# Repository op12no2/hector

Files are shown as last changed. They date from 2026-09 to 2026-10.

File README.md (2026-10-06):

## Hector

A little hexapod.

### Parts

- 12 off [SC09 Serial Bus Servo (2.3kg)](https://thepihut.com/products/serial-bus-servo-2-3kg)
- [M5Stack ATOM S3R](https://thepihut.com/products/atoms3r-development-kit-with-0-85-display-8mb-psram)
- [MPM3610 5V Buck Converter Breakout - 21V In 5V Out at 1.2A](https://thepihut.com/products/adafruit-mpm3610-5v-buck-converter-breakout-21v-in-5v-out-at-1-2a)
- 2S LiPo
- Small Schottky diode (SS14, 1N5817), a switch (or XT30 plug) and optionally a ~5 A fuse
- Sensor TBD

### Wiring

See [wiring.md](wiring.md): the ATOM drives the bus through the adapter's UART header (jumper in A), powered from the battery through the buck and a diode, which leaves its USB-C free for flashing.

### Chassis

See `cad` folder above. I used a Bambu P2S.

### Software

`hector.c` drives the servos from a Raspberry Pi 5 through a [Waveshare Serial Bus Servo Driver Board](https://thepihut.com/products/serial-bus-servo-driver-board) (USB, jumper in B). It's a copy of the [servo](https://github.com/op12no2/servo) tester, so all of its commands (`ping`, `stat`, `move`, `torque`, `limits`, ...) work here too, plus the hexapod commands below.

```
make
./hector [/dev/ttyACM0] [baud]     # default 1000000
```

The same `hector.c` also builds for the ATOM S3R (ESP-IDF, in `atom/`), which drives the bus through the adapter's UART header (jumper in A, see [wiring.md](wiring.md)), with the REPL on the ATOM's USB:

```
cd atom
source ~/esp/esp-idf/export.sh
idf.py build
idf.py -p /dev/serial/by-id/usb-Espressif_* flash monitor     # ctrl-] leaves the monitor
```

At power-on the ATOM runs the checks, stands up unless something failed, runs the standing checks, then shows its face: two eyes and a mouth, turned so the mouth points at its front (someone standing there sees it upright). The eyes blink and glance about while it waits for a command; if something's wrong the whites go yellow or red, the mouth goes flat or frowns, and the problem shows along the bottom. While it waits it also watches the servos (a low or flat battery, heat, error bits, a load held high, a servo not replying: shown under the eyes, and for the serious ones it sits down), and while it's standing, lift it at an edge and put it down: it walks away from that edge (away from you) for 5 seconds, with the current gait and stride. It sets off within about half a second of being put down. The gap opposite the lifted edge becomes its front, and the face turns there while it's still lifted, so you can see where it will go. Sliding it along the desk does nothing. There are no safety stops for now (nothing waits for hands to be clear, and it doesn't go limp if a leg meets something while walking): a key stops a walk and ctrl-c freezes it. Knocked over, it sits. Every command works the same way there; `quit` has nothing to quit to, and changes to `offset[]` last until the ATOM resets. Any terminal on its USB port works as well as `idf.py monitor` (e.g. `picocom /dev/ttyACM0`), but opening the port with `idf.py monitor` resets the ATOM.

Leg *n* is hip (yaw) servo *n* and lift servo *n*+6. Where each leg is, and which way each servo turns, is set in `legs[]` at the top of the hexapod section of `hector.c`.

`offset[]`, just above it, is a per-servo offset added to every goal position sent, by `move` as well as the hexapod commands, so with an offset of 20 on servo 7, `move 7 511` sends 531. The lifts' offsets come from `calibrate`. `offset` and `calibrate` change it until you exit; they print the table as a line of C to paste into `hector.c` to keep it. `pos`, `stat` and `move`'s check report the servo's actual position, with the offset included; `ww` to the goal register doesn't add it.

| Command | Description |
|---|---|
| `stand [ms]` | all feet down, hips centred, taking ms (default 1000) |
| `front [1-6]` | show or set the walk's front: gap k, between legs k and k+1 (gap 6, legs 6 and 1, after a reset). A tip sets it too (it walks away from the lifted edge), and the face turns to it |
| `sit [ms]` | all six lifts up to 1000, taking ms (default 1000), the same as `move 7-12 1000 1000`: the body sits on the ground with the legs pointing up inside it, so there's no load on the servos. Do it before switching off; `stand` gets up again |
| `legtest [1-6]` | each leg in turn (or one, by hip id): lift servo up to 700, forward 80, back, down to its stance pose; the other legs stay where they are |
| `ident [id]` | twitch each id (default 1-12) in turn, a second apart, to see which servo has which id: 30 steps up from where it is and back; it prints which leg `legs[]` says the id belongs to |
| `offset [id val]` | show the per-servo offsets, or set one; the change lasts until exit |
| `calibrate` | stand, then nudge the lift offsets, a step or two at a time from where they are, until all six feet carry the same load (within 1.5%); prints the offset table to paste into `hector.c` |
| `walk [cycles] [stride] [turn]` | stand, then walk with the current gait; stride < 0 walks backwards, turn > 0 turns left (stride 0 turns on the spot); with no cycles it walks until a key is pressed; a key stops it gracefully (legs step back to centre), ctrl-c freezes it where it is; afterwards it prints each servo's peak load (a servo held over 80% for 4 s drops to 20% torque) and the longest tick (they should be 20 ms). The face holds still while it walks |
| `set [name value]` | list or set walk parameters (below) |
| `loads [secs]` | stream every servo's load and position error (goal and position both read from the servo) as fast as the bus allows, about 80 sweeps of all 12 a second, for secs seconds (default 10) or until a key; reads only, so stand first. The ATOM's screen shows the seconds, to time presses by |
| `imu [secs]` | stream the ATOM's IMU (BMI270) at 50 lines a second: acceleration (g) and rotation (deg/s), with x towards the gap between legs 1 and 2, y 90° anticlockwise from it seen from above and z up, and the tilt from the first reading; default 10 s, or until a key |
| `selftest` | the checks it runs at startup, again (they only read, nothing moves). Before standing (the go/no-go for standing up): the screen and the IMU answer (ATOM only), every servo replies, battery (warns under 7.0 V, fails under 6.6), temperature, error bits, overload protection at the defaults, the gains (P 15, D 15, I 1 on the lifts and 0 on the hips), positions inside the range the legs are driven over. Standing (only if `stand` ran last, not `sit`): the load on each foot (warns if one is over 5% off the mean: calibrate), sag (a foot pushed up over 6 steps from its goal), level (IMU, warns over 5°), the highest load on any servo, the battery under load. On the ATOM each check also goes up on the screen as it runs, then the eyes come back, their whites yellow with warnings or red with failures, with the first problem under them |

| Parameter | Default | |
|---|---|---|
| `gait` | tripod | `wave` (1 leg up at a time), `ripple` (2) or `tripod` (3) |
| `step` | 800 | ms each leg spends in the air (a cycle is 6 steps in wave, 3 in ripple, 2 in tripod) |
| `stride` | 50 | hip swing either side of centre, servo steps (0.29° each) |
| `lift` | 70 | foot lift during a step, steps |
| `height` | 0 | legs this far below centre when standing, -150..50: > 0 raises the body, < 0 lowers it with the legs splayed (the legs reach the chassis at about 50 below) |

First run: prop the body up so the feet are off the ground, `legtest`, and check that each leg lifts *up* and swings *forward*, and that the leg that moves is the one named. Fix `legs[]` if not. Then put it down and `walk 2`.

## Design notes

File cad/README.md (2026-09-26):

## CAD

Each part is here twice: `.step` (the model, for measuring or editing) and `.stl` (the same part laid flat for printing). Units are mm. The STEP files come from Open CASCADE 7.8.

| Part | What it is |
|---|---|
| `04_six_leg_platform` | the body: a 220 mm disc, 3 mm thick, with six spokes carrying the hip servo pockets, and a central wiring cage |
| `06_electronics_lid` | a 100 mm disc that closes the top of the cage |
| `02_hip_cradle` | bolts to a hip servo's horn and holds that leg's lift servo on its side (×6) |
| `03_fixed_leg` | a 4 mm plate on the lift servo's horn, running out about 28 mm and then bending down to a rounded foot (×6) |
| `05_one_hip_assembly` | the body and lid with one leg fitted (hip and lift servos, horns, cradle, leg), as named parts; STEP only |

The parts share one coordinate frame: body centre on the z axis, the underside of the plate at z = 0 (the assembly sits 0.8 mm lower than the loose cradle and leg files).

### Body

- **Plate:** an outer ring (r 102–110) joined to a hub by six spokes, with big lightening windows between them. Each spoke carries a hip servo pocket, and two 3 mm ribs on top run along it either side of the servo. A 10 mm hole in the middle.
- **Cage:** a tube, 100 mm across and 1.6 mm wall, standing 63 mm above the underside of the plate, with rows of slots round it for wires. The lid's 4 mm spigot drops into its top.
- **Inside the cage:** six pairs of M3 holes, 8 mm apart, on a 70 mm circle (one pair in line with each leg), for the electronics.

### How it goes together

- **Legs:** six, 60° apart. The middle legs are on the x axis, so forward is along y. The front and rear legs are 60° either side of the middle ones.
- **Hip servos:** each sits in a pocket, hanging under the plate (to 18.5 mm below it), with its mounting holes (M2) 70 and 98.5 mm from the centre. The shaft is 90 mm from the centre (the SC09's shaft is 5.65 mm off the midpoint of its mounting holes). The hip axis is vertical.
- **Lift servos:** the cradle holds each one with its axis horizontal, directly above the hip axis, 12 mm above the cradle's underside and 23 mm above the underside of the plate.
- **Leg plates:** each sits about 18 mm along the lift axis from the hip axis, so the foot is offset sideways from the hip, not straight out from it.
- **Horns:** the servo horns take a 6 mm hub with two M2 screws 19.8 mm apart (the holes in the cradle base and the leg).

### Leg geometry

With the leg as drawn (taken to be the 511 pose), the bottom of the foot is 42.5 mm out from the lift axis and 81 mm below it, 91.5 mm in all (the old, shorter leg was 41 and 71). The lift servo turns the whole leg about that axis, so `height` in `hector.c` (one step = 0.293°) moves the foot like this, with the body's height off the ground on level feet:

| `height` | Foot out from lift axis | Foot below lift axis | Plate underside off the ground | Hip servos off the ground |
|---|---|---|---|---|
| +50 | 21 | 89 | 66 | 47 |
| 0 | 42 | 81 | 58 | 39 |
| −60 | 65 | 64 | 41 | 23 |
| −100 | 77 | 50 | 27 | 8 |
| −120 | 81 | 42 | 19 | 0 |

Below about −120 the hip servos, not the feet, touch the ground. The second column is the lever arm the lift servo works against: its torque is the weight on that foot times this distance. A lower, more splayed body means more torque, up to 91.5 mm when the foot is level with the axis.

### Clearances

Measured by turning the parts in the assembly, so only as good as the "as drawn = 511" assumption:

- **Lift, foot down (`height` > 0):** the leg reaches the outer ring of the plate at about 26° (89 steps). The old body measured 92 steps the same way, yet the legs met the chassis at about 50 on the robot, so the drawn pose is probably not exactly 511; expect about the same margin as before.
- **Lift, foot up:** nothing in the way.
- **Hip, towards the side of the hip the leg plate is on:** the leg's lower half reaches the outer ring, sooner the lower the foot: about 61 steps at `height` +50, 123 at 0, 177 at −60 and 218 at −100 (the old body: 75, 137 and 198). The other way it's clear to about 90°. All six legs are fitted the same way round, so that's the same sense of rotation for every hip (anticlockwise from above in these files): forward on one side of the robot and back on the other. As `hip_dir` is −1 on the left and +1 on the right, it's also either a higher position for every hip or a lower one.
- **Neighbouring legs:** they don't meet, with each hip turned up to 118° towards the other.

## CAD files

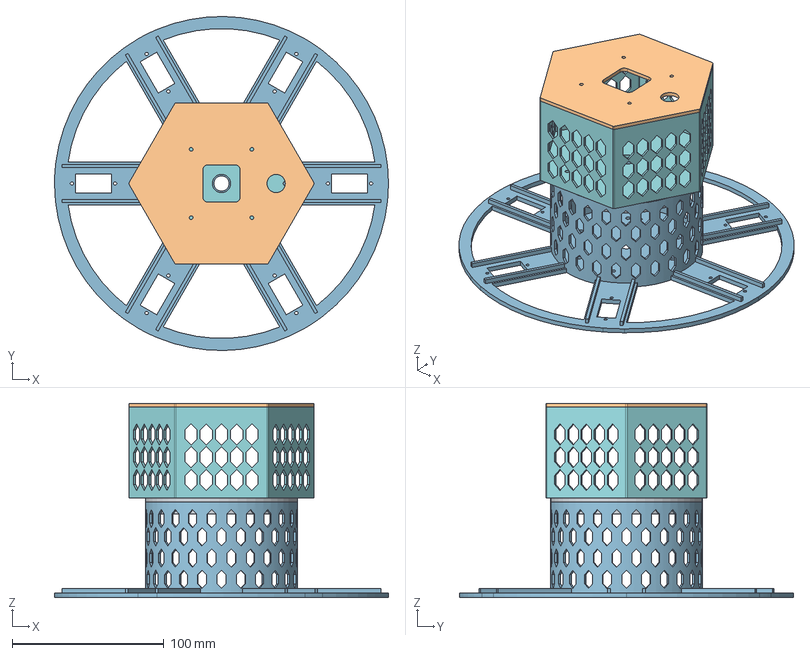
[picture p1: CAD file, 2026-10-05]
cad/11_extended_body_assembly.step
220.0 x 220.0 x 127.8 mm
adapter
upper_cage
hex_lid

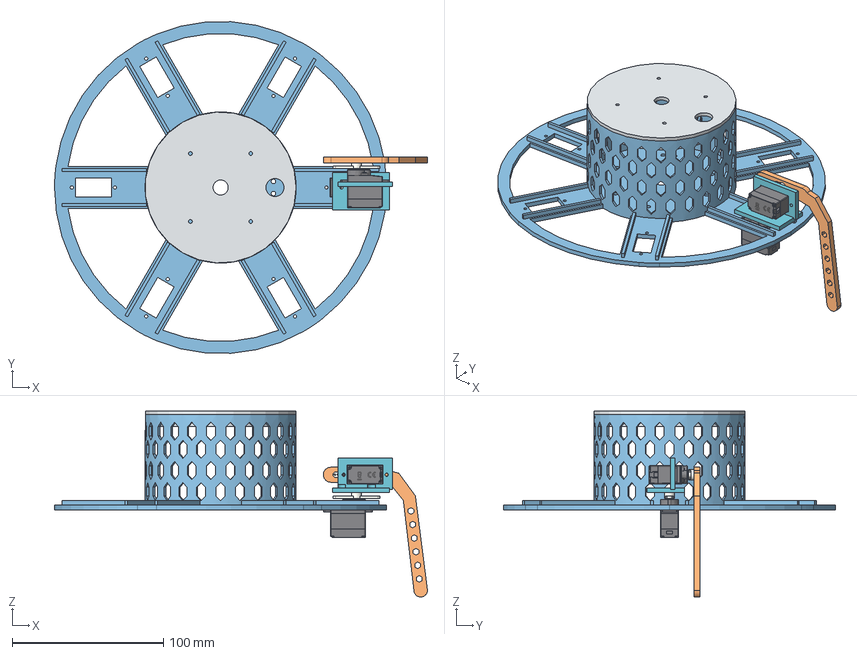
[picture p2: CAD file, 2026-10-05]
cad/05_one_hip_assembly.step
247.0 x 219.6 x 123.2 mm
lid
cradle
leg
yaw_servo
pitch_servo
yaw_horn
pitch_horn

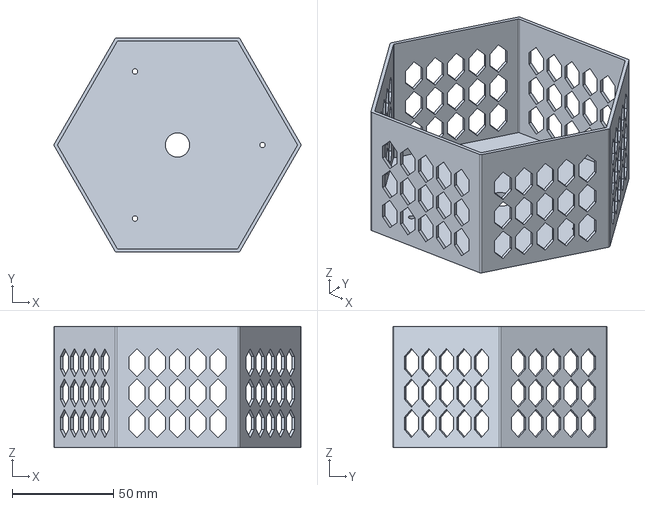
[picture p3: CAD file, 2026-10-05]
cad/07_hex_upper_cage.step
122.1 x 106.0 x 60.0 mm

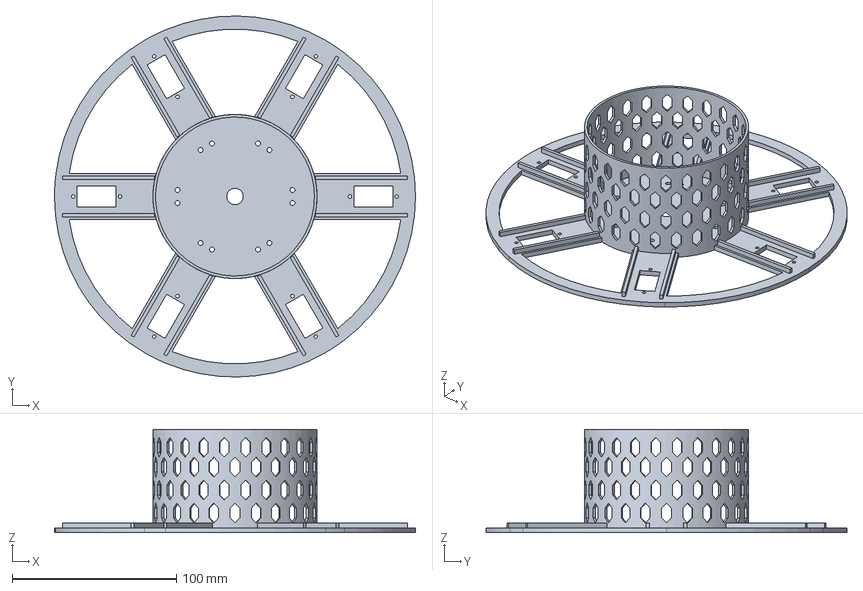
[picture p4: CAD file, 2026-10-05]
cad/04_six_leg_platform.step
220.0 x 220.0 x 63.0 mm

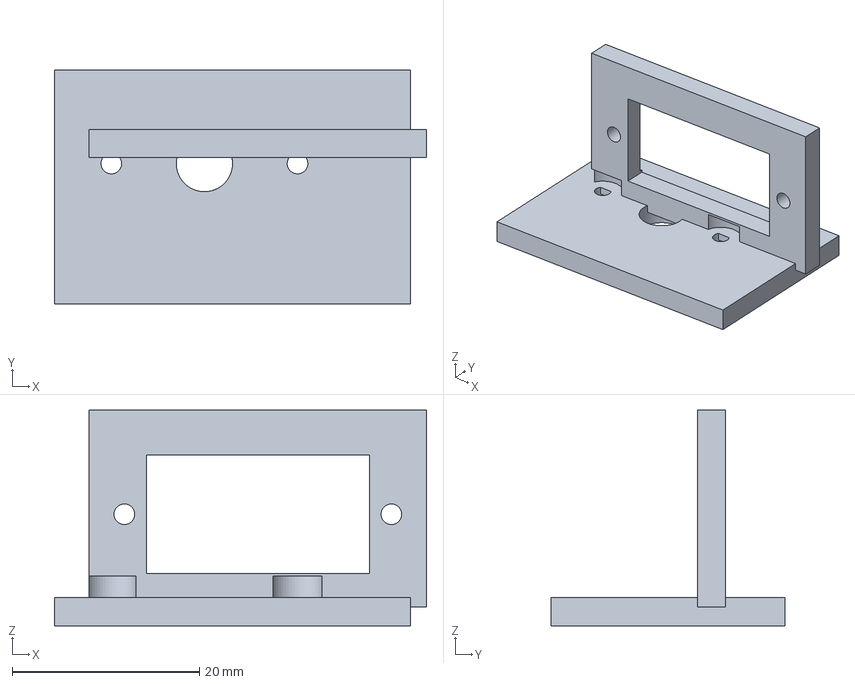
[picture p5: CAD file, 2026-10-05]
cad/02_hip_cradle.step
39.7 x 25.0 x 23.0 mm

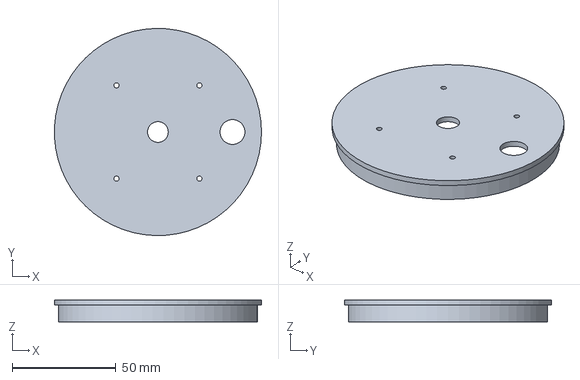
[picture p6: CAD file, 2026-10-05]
cad/06_electronics_lid.step
99.9 x 100.0 x 10.4 mm

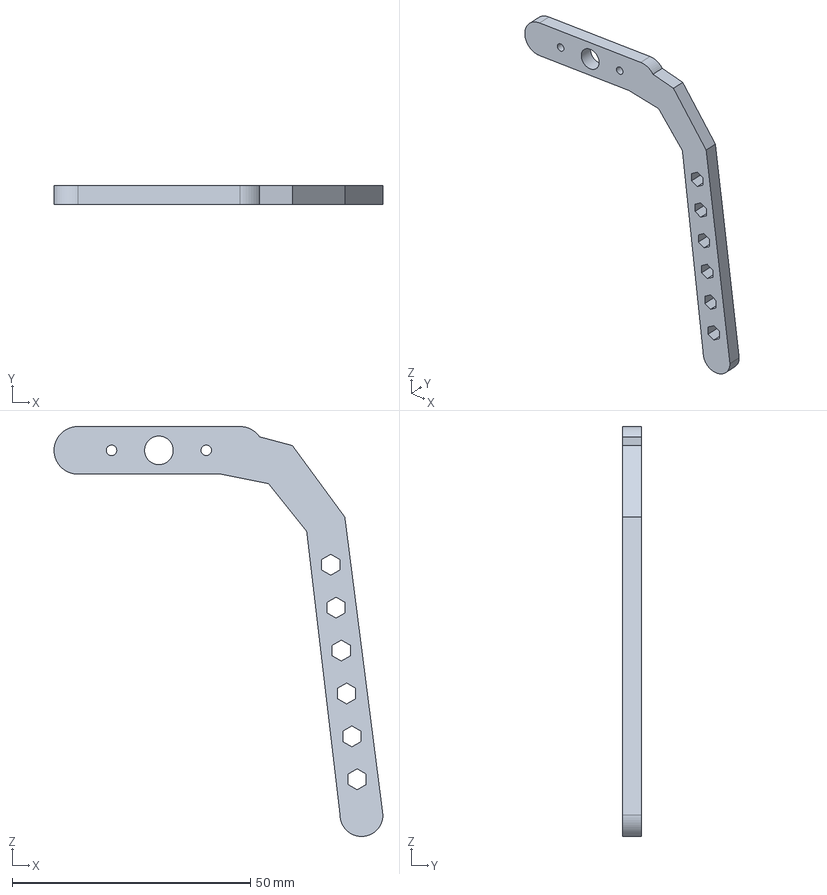
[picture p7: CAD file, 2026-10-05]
cad/03_fixed_leg.step
69.0 x 4.00 x 86.0 mm

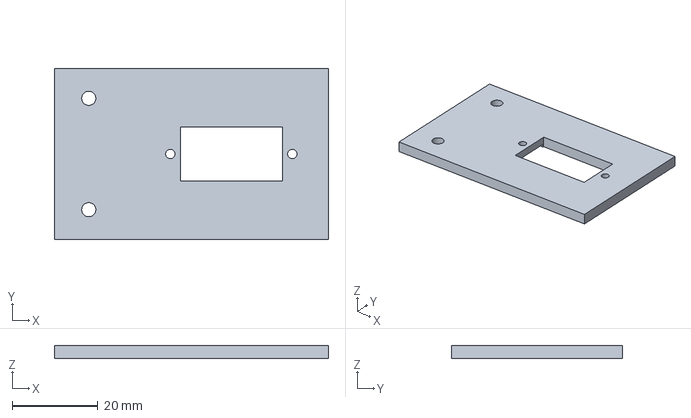
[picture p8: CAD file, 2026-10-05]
cad/01_bench_mount.step
64.0 x 40.0 x 3.00 mm

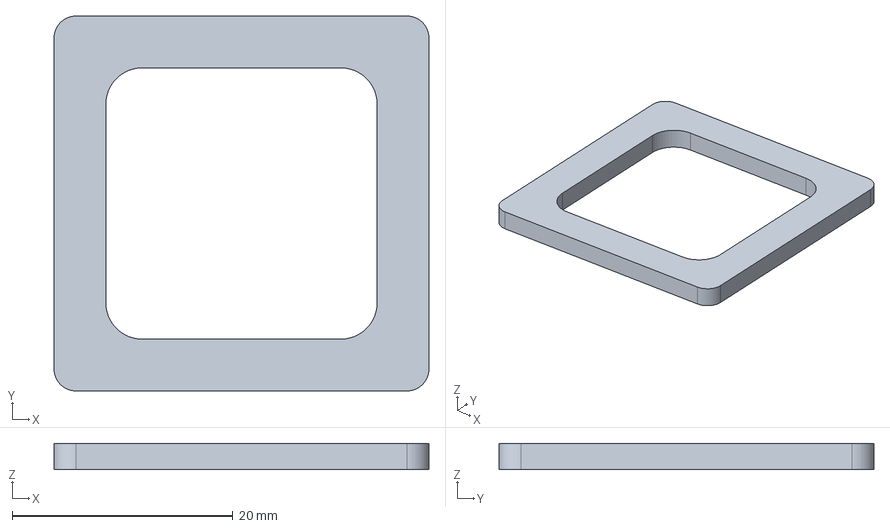
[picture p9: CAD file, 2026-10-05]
cad/10_atom_fit_test.step
34.0 x 34.0 x 2.40 mm

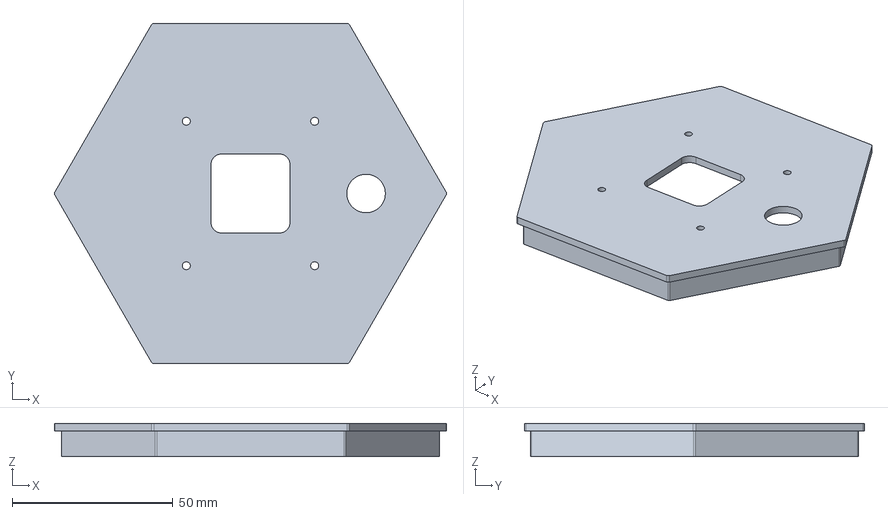
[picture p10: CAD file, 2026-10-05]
cad/09_hex_atom_lid.step
122.1 x 106.0 x 10.4 mm

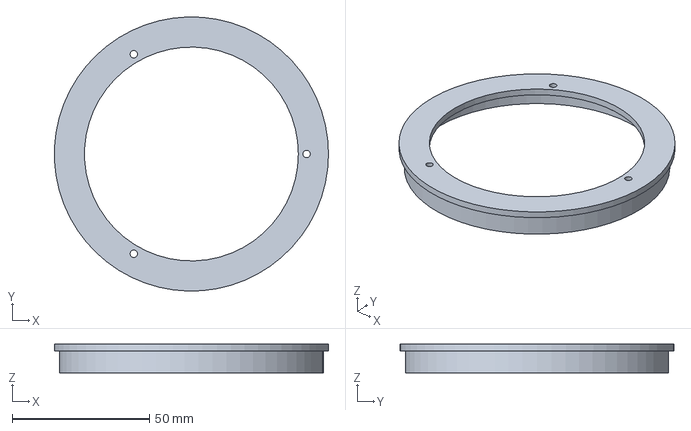
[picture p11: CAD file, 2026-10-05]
cad/08_circular_adapter.step
99.9 x 100.0 x 10.4 mm

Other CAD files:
cad/01_bench_mount.stl
cad/02_hip_cradle.stl
cad/03_fixed_leg.stl
cad/04_six_leg_platform.stl
cad/06_electronics_lid.stl
cad/07_hex_upper_cage.stl
cad/08_circular_adapter.stl
cad/09_hex_atom_lid.stl
cad/10_atom_fit_test.stl

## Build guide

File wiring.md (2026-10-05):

## Wiring: ATOM S3R

wiring

The ATOM talks to the bus over a GPIO UART into the adapter's UART header (H2), with the adapter's jumper in **A**. That leaves the ATOM's USB-C free for flashing and the console, even while it walks (tethered). The Pi's USB lead can stay plugged into the adapter: the jumper picks which one drives the bus (**A** = H2, the ATOM; **B** = USB, the Pi).

### Wires

| From | To | |
|---|---|---|
| battery + | SW1, F1, then adapter + **and** U1 Vin | VBAT, 20 AWG or thicker to the adapter |
| battery − | adapter − **and** U1 GND | |
| U1 5V | D1 anode | |
| D1 cathode | ATOM 5V | about 4.7 V |
| U1 GND | ATOM GND | |
| ATOM G38 (TX) | H2 TXD | |
| ATOM G39 (RX) | H2 RXD | |
| ATOM GND | H2 GND | run it with TX and RX |
| U1 En | nothing | pulled up to Vin on the breakout |

G39, G38, 5V and GND are the ATOM's right-hand header, in that order, so a single 4-way housing takes all of them. That leaves Port A (Grove: G2 SDA, G1 SCL, 5V, GND) for the sensor, and G5–G8 on the other header free.

H2 is a 3-pin header, GND, RXD, TXD. The names are from the host's side, so it's RXD to RX and TXD to TX, not crossed ("RX-RX, TX-TX" in Waveshare's wiki). If nothing replies, swapping them does no harm.

In code: `Serial1.begin(1000000, SERIAL_8N1, 39, 38);` (rx, tx).

### Why

- **The ATOM needs the buck.** Its 5V pin goes straight to its 5 V rail (the same net as USB VBUS, behind a 6 V polyfuse) and from there to a 5.5 V-max 3.3 V regulator, so 8.4 V from the battery would kill it. The adapter does have a 5 V buck and a 3.3 V regulator on board, but only for its own logic: they aren't brought out. U1 (the MPM3610 in the parts list) takes 6–21 V and gives 5 V at 1.2 A, plenty for the ATOM and a sensor.
- **D1** (any small Schottky, e.g. SS14 or 1N5817). Because the ATOM's 5V pin is its USB VBUS, with the battery on and USB plugged in, U1 and the computer's USB port would be wired together. With D1, U1 gives about 4.7 V; USB's 5 V wins when it's plugged in and D1 blocks it from feeding back into U1. Without D1, never plug USB in with the battery on.
- **No level shifting.** The adapter's UART side is 3.3 V (74LVC1G125/126 buffers on its own 3.3 V regulator), the same as the ESP32-S3. While the ATOM is resetting and G38 floats, the adapter's transmit enable is pulled off, so the bus just stays in receive.
- **Not the USB port.** The ATOM's USB-C is its only way to flash and see a console. Using it for the bus would mean USB host mode and a CH343 driver on the ESP32-S3, and unplugging the adapter every time you flash.
- **Battery voltage** comes from the servos' voltage register (0x3E, as `stat` and `check_servos()` read it), so no divider on an ADC pin. 2S is low at about 7.0 V under load.
- **SW1 and F1.** SW1 (or an XT30 plug) switches the servos and the ATOM together; it carries all the servo current, so a few amps. F1 is optional, but a LiPo will melt wire in a short, and the wiring cage is tight; about 5 A (the adapter is rated 6 A).

### Bringing it up

1. Before connecting the ATOM: battery on, check U1 + D1 give about 4.7 V, positive on the D1 cathode side. U1 has no reverse-polarity protection (the adapter does).
2. Connect the ATOM. It should boot from the battery, with or without USB.
3. Jumper to A, then flash `atom/` (see the README) and `ping` (2026-10-02: all 12 servos replied, with USB powering the ATOM and the buck's 5V lead off while D1 was on order; D1 was fitted by 2026-10-05).
4. Back to the Pi: jumper to B. The ATOM can stay wired.

### Sources

- [ATOM S3R](https://docs.m5stack.com/en/core/AtomS3R): [schematic](https://m5stack-doc.oss-cn-shenzhen.aliyuncs.com/680/Sch_M5_AtomS3R_v0.4.1.pdf), [pin map](https://m5stack-doc.oss-cn-shenzhen.aliyuncs.com/680/C126_PinMap_01.jpg)
- [Bus Servo Adapter (A)](https://www.waveshare.com/wiki/Bus_Servo_Adapter_(A)): [schematic](https://files.waveshare.com/wiki/Bus_Servo_Adapter_A/Bus_Servo_Adapter_A.pdf), [wiring example](https://docs.waveshare.com/Bus_Servo_Adapter_A/Product-Wiring-Example)
- [MPM3610 breakout](https://www.adafruit.com/product/4739): [PCB files](https://github.com/adafruit/Adafruit-MPM3610-PCB) (pins GND, 5V, Vin, En; En pulled up to Vin)

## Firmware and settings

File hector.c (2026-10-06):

/*
 * hector.c - Hector the hexapod: 12 Waveshare SC09 bus servos via a
 * Waveshare Bus Servo Adapter (A) / USB serial. Started as a copy of
 * ../servo/servo.c (the generic servo tester) and keeps all its commands;
 * the hexapod commands (stand, sit, front, legtest, ident, offset, calibrate,
 * walk, set, loads, imu, selftest) are at the end.
 *
 * Build:  make
 * Run:    ./hector [/dev/ttyACM0] [baud]
 * Then type commands on stdin ("help" lists them).
 *
 * The same file builds for the ATOM S3R (ESP-IDF, atom/): the bus is then
 * UART1 on G38/G39 into the adapter's UART header and the console is the
 * ATOM's USB. Only the I/O section below differs (ESP_PLATFORM).
 *
 * Protocol:
 *   TX: FF FF ID LEN INSTR PARAM... CHK     LEN = nparams + 2
 *   RX: FF FF ID LEN ERR   PARAM... CHK
 *   CHK = ~(ID + LEN + INSTR/ERR + sum(PARAM)) & 0xFF
 * 16-bit registers are high byte first.
 */
#include <errno.h>
#include <math.h>
#include <stdarg.h>
#include <stdio.h>
#include <stdlib.h>
#include <string.h>
#include <time.h>
#include <unistd.h>
#ifdef ESP_PLATFORM
#include "driver/gpio.h"
#include "driver/i2c_master.h"
#include "driver/spi_master.h"
#include "driver/uart.h"
#include "driver/usb_serial_jtag.h"
#include "driver/usb_serial_jtag_vfs.h"
#include "freertos/FreeRTOS.h"
#include "freertos/task.h"
#else
#include <fcntl.h>
#include <signal.h>
#include <termios.h>
#include <sys/select.h>
#include <sys/time.h>
#endif

#define INST_PING       0x01
#define INST_READ       0x02
#define INST_WRITE      0x03
#define INST_SYNC_WRITE 0x83
#define BROADCAST       0xFE

/* SC09 register map */
#define REG_ID            0x05
#define REG_MIN_ANGLE     0x09  /* u16 */
#define REG_MAX_ANGLE     0x0B  /* u16 */
#define REG_DEADZONE_CW   0x1A
#define REG_DEADZONE_CCW  0x1B
#define REG_TORQUE_ENABLE 0x28
#define REG_GOAL_POS      0x2A  /* u16 */
#define REG_GOAL_TIME     0x2C  /* u16 */
#define REG_GOAL_SPEED    0x2E  /* u16 */
#define REG_LOCK          0x30  /* EPROM lock: 1=locked, 0=unlocked */
#define REG_PRESENT_POS   0x38  /* u16 */
#define REG_PRESENT_SPEED 0x3A  /* u16 */
#define REG_PRESENT_LOAD  0x3C  /* u16 */
#define REG_VOLTAGE       0x3E
#define REG_TEMP          0x3F
#define REG_MOVING        0x42

static int verbose = 0;
static int timeout_ms = 50;

/* 16-bit register values are high byte first */
static int get16(const unsigned char *b) { return b[0] << 8 | b[1]; }
static void put16(unsigned char *b, int v) { b[0] = v >> 8; b[1] = v; }

static void die(const char *fmt, ...)
{
    va_list ap; va_start(ap, fmt); vfprintf(stderr, fmt, ap); va_end(ap);
    fputc('\n', stderr); exit(1);
}

/*
 * ---- I/O ----
 * The servo bus (open_port, bus_flush, bus_write, read_bytes), the console
 * (con_*), timing (msleep, tick_*), the screen (scr_*) and the IMU (imu_*):
 * the last two are the ATOM's, stubs on the Pi. Everything else is the same on the Pi and the ATOM.
 */
#ifdef ESP_PLATFORM

/* ATOM S3R: UART1, TX G38 to the adapter's H2 TXD, RX G39 from its RXD (jumper in A) */
#define BUS_UART UART_NUM_1
#define BUS_TX   38
#define BUS_RX   39
#define BUS_ECHO 0      /* the H2 link doesn't loop TX back to RX, so txrx() doesn't read for an echo (which costs a timeout per write) */

static void open_port(const char *dev, int baud)
{
    (void)dev;
    uart_config_t c = {
        .baud_rate = baud, .data_bits = UART_DATA_8_BITS, .parity = UART_PARITY_DISABLE,
        .stop_bits = UART_STOP_BITS_1, .flow_ctrl = UART_HW_FLOWCTRL_DISABLE, .source_clk = UART_SCLK_DEFAULT,
    };
    if (uart_driver_install(BUS_UART, 1024, 0, 0, NULL, 0) != ESP_OK || uart_param_config(BUS_UART, &c) != ESP_OK ||
        uart_set_pin(BUS_UART, BUS_TX, BUS_RX, UART_PIN_NO_CHANGE, UART_PIN_NO_CHANGE) != ESP_OK)
        die("uart setup failed");
    gpio_set_pull_mode(BUS_RX, GPIO_PULLUP_ONLY);
}

static void bus_flush(void) { uart_flush_input(BUS_UART); }

static void bus_write(const unsigned char *b, int n)
{
    uart_write_bytes(BUS_UART, b, n);
    uart_wait_tx_done(BUS_UART, portMAX_DELAY);
}

/* read n bytes or time out; returns bytes read */
static int read_bytes(unsigned char *buf, int n, int ms)
{
    int r = uart_read_bytes(BUS_UART, buf, n, pdMS_TO_TICKS(ms));
    return r < 0 ? 0 : r;
}

/*
 * The console is the ATOM's USB (USB-Serial/JTAG). It has no termios and no
 * SIGINT, so it is always "raw", and ctrl-c arrives as a byte (walk checks).
 */
static int con_block = 1;

static void con_init(void)
{
    usb_serial_jtag_driver_config_t c = USB_SERIAL_JTAG_DRIVER_CONFIG_DEFAULT();
    usb_serial_jtag_driver_install(&c);
    usb_serial_jtag_vfs_use_driver();
}

static int con_tty(void) { return 1; }
static void con_raw(int block) { con_block = block; }
static void con_restore(void) { con_block = 1; }

/* next byte; with con_raw(0), -1 if there isn't one */
static int con_getc(void)
{
    unsigned char c;
    return usb_serial_jtag_read_bytes(&c, 1, con_block ? portMAX_DELAY : 0) == 1 ? c : -1;
}

/* next byte within ms, or -2 if none came (for the idle loop) */
static int con_getc_ms(int ms)
{
    unsigned char c;
    return usb_serial_jtag_read_bytes(&c, 1, pdMS_TO_TICKS(ms)) == 1 ? c : -2;
}

/* drop typed-ahead input */
static void con_drop(void)
{
    unsigned char c;
    while (usb_serial_jtag_read_bytes(&c, 1, 0) == 1) ;
}

static volatile int halted;
static void sigint_catch(void) {}
static void sigint_restore(void) {}

static void msleep(int ms) { vTaskDelay(pdMS_TO_TICKS(ms)); }

/* fixed-rate ticks for walk: tick_start, then tick_wait(ms) each tick; tick_start again to resync */
static TickType_t tick_last;
static void tick_start(void) { tick_last = xTaskGetTickCount(); }
static void tick_wait(int ms) { xTaskDelayUntil(&tick_last, pdMS_TO_TICKS(ms)); }

/*
 * The screen: 0.85" 128x128 on SPI (MOSI G21, SCLK G15, CS G14, DC G42, RST G48).
 * The panel is a GC9107, or an ST7735S on some batches, told apart by RDDID as
 * M5GFX does (init sequences and offsets are from M5GFX too). The backlight is
 * an LP5562 LED driver on the internal I2C (SDA G45, SCL G0), which the IMU shares.
 * Drawing goes into fb[], and scr_show() sends all of it (32 KB, about 7 ms).
 */
#define LCD_HOST SPI3_HOST
#define LCD_MOSI 21
#define LCD_SCLK 15
#define LCD_CS   14
#define LCD_DC   42
#define LCD_RST  48
#define SYS_SDA  45     /* the internal I2C: backlight and IMU */
#define SYS_SCL  0
#define BL_ADDR  0x30   /* LP5562 */
#define BL_LEVEL 160    /* 0..255 */

static spi_device_handle_t lcd;
static int lcd_x0, lcd_y0;              /* where the 128x128 window starts in the controller's memory */
static uint16_t fb[128 * 128];          /* RGB565, byte-swapped: sent high byte first */

/*
 * Init lists: command, number of parameters (| 0x80 if a delay follows),
 * parameters, then the delay in ms (255 = 500); 0xFF ends the list.
 */
static const unsigned char gc9107_init[] = {
    0xFE, 0x80, 5,
    0xEF, 0x80, 5,
    0xB0, 1, 0xC0,  0xB2, 1, 0x2F,  0xB3, 1, 0x03,  0xB6, 1, 0x19,  0xB7, 1, 0x01,
    0xAC, 1, 0xCB,  0xAB, 1, 0x0E,  0xB4, 1, 0x04,  0xA8, 1, 0x19,  0xB8, 1, 0x08,
    0xE8, 1, 0x24,  0xE9, 1, 0x48,  0xEA, 1, 0x22,  0xC6, 1, 0x30,  0xC7, 1, 0x18,
    0xF0, 14, 0x01, 0x2B, 0x23, 0x3C, 0xB7, 0x12, 0x17, 0x60, 0x00, 0x06, 0x0C, 0x17, 0x12, 0x1F,
    0xF1, 14, 0x05, 0x2E, 0x2D, 0x44, 0xD6, 0x15, 0x17, 0xA0, 0x02, 0x0D, 0x0D, 0x1A, 0x18, 0x1F,
    0x11, 0x80, 120,                    /* sleep out */
    0x29, 0,                            /* display on */
    0x3A, 1, 0x55,                      /* 16-bit colour */
    0x36, 1, 0x08,                      /* MADCTL: BGR */
    0x20, 0,                            /* inversion off */
    0xFF,
};
static const unsigned char st7735s_init[] = {
    0x01, 0x80, 150,                    /* software reset */
    0x11, 0x80, 255,                    /* sleep out */
    0xB1, 3, 0x01, 0x2C, 0x2D,
    0xB2, 3, 0x01, 0x2C, 0x2D,
    0xB3, 6, 0x01, 0x2C, 0x2D, 0x01, 0x2C, 0x2D,
    0xB4, 1, 0x07,
    0xC0, 3, 0xA2, 0x02, 0x84,  0xC1, 1, 0xC5,  0xC2, 2, 0x0A, 0x00,  0xC3, 2, 0x8A, 0x2A,
    0xC4, 2, 0x8A, 0xEE,  0xC5, 1, 0x0E,
    0xE0, 16, 0x02, 0x1C, 0x07, 0x12, 0x37, 0x32, 0x29, 0x2D, 0x29, 0x25, 0x2B, 0x39, 0x00, 0x01, 0x03, 0x10,
    0xE1, 16, 0x03, 0x1D, 0x07, 0x06, 0x2E, 0x2C, 0x29, 0x2D, 0x2E, 0x2E, 0x37, 0x3F, 0x00, 0x00, 0x02, 0x10,
    0x13, 0x80, 10,                     /* normal display on */
    0x29, 0x80, 100,                    /* display on */
    0x3A, 1, 0x55,                      /* 16-bit colour */
    0x36, 1, 0xDC,                      /* MADCTL: rotated 180, BGR */
    0x21, 0,                            /* inversion on */
    0xFF,
};

/* the panel's id (RDDID, 3-wire: one dummy bit, then 32 bits back on MOSI) */
static uint32_t lcd_id(int hz)
{
    spi_device_interface_config_t d = {
        .command_bits = 8, .dummy_bits = 1, .clock_speed_hz = hz, .spics_io_num = LCD_CS,
        .queue_size = 1, .flags = SPI_DEVICE_3WIRE | SPI_DEVICE_HALFDUPLEX,
    };
    spi_device_handle_t h;
    if (spi_bus_add_device(LCD_HOST, &d, &h) != ESP_OK) return 0;
    spi_transaction_t t = { .cmd = 0x04, .rxlength = 32, .flags = SPI_TRANS_USE_RXDATA };
    uint32_t id = 0;
    gpio_set_level(LCD_DC, 0);
    if (spi_device_polling_transmit(h, &t) == ESP_OK)
        id = t.rx_data[0] | t.rx_data[1] << 8 | t.rx_data[2] << 16 | (uint32_t)t.rx_data[3] << 24;
    spi_bus_remove_device(h);
    return id;
}

/* dc 0 = command, 1 = data */
static void lcd_send(int dc, const void *p, int n)
{
    spi_transaction_t t = { .length = n * 8, .tx_buffer = p };
    gpio_set_level(LCD_DC, dc);
    spi_device_polling_transmit(lcd, &t);
}

static void lcd_cmds(const unsigned char *c)
{
    while (*c != 0xFF) {
        unsigned char cmd = *c++, n = *c++, par[32];
        if ((n & 0x7F) > sizeof par) die("lcd init list: %d parameters", n & 0x7F);
        lcd_send(0, &cmd, 1);
        memcpy(par, c, n & 0x7F);           /* via RAM: DMA can't read flash */
        if (n & 0x7F) lcd_send(1, par, n & 0x7F);
        c += n & 0x7F;
        if (n & 0x80) { int ms = *c++; msleep(ms == 255 ? 500 : ms); }
    }
}

/*
 * 5x7 font, ' ' to '~', a byte per column, bit 0 at the top. From Adafruit GFX's
 * glcdfont.c: Copyright (c) 2012 Adafruit Industries. All rights reserved.
 * BSD licence: redistributions must keep this notice. THIS SOFTWARE IS PROVIDED
 * BY THE COPYRIGHT HOLDERS AND CONTRIBUTORS "AS IS" AND ANY EXPRESS OR IMPLIED
 * WARRANTIES ARE DISCLAIMED (full text in Adafruit-GFX-Library's glcdfont.c).
 */
static const unsigned char font5x7[95][5] = {
    { 0x00, 0x00, 0x00, 0x00, 0x00 },  /* ' ' */
    { 0x00, 0x00, 0x5F, 0x00, 0x00 },  /* '!' */
    { 0x00, 0x07, 0x00, 0x07, 0x00 },  /* '"' */
    { 0x14, 0x7F, 0x14, 0x7F, 0x14 },  /* '#' */
    { 0x24, 0x2A, 0x7F, 0x2A, 0x12 },  /* '$' */
    { 0x23, 0x13, 0x08, 0x64, 0x62 },  /* '%' */
    { 0x36, 0x49, 0x56, 0x20, 0x50 },  /* '&' */
    { 0x00, 0x08, 0x07, 0x03, 0x00 },  /* "'" */
    { 0x00, 0x1C, 0x22, 0x41, 0x00 },  /* '(' */
    { 0x00, 0x41, 0x22, 0x1C, 0x00 },  /* ')' */
    { 0x2A, 0x1C, 0x7F, 0x1C, 0x2A },  /* '*' */
    { 0x08, 0x08, 0x3E, 0x08, 0x08 },  /* '+' */
    { 0x00, 0x80, 0x70, 0x30, 0x00 },  /* ',' */
    { 0x08, 0x08, 0x08, 0x08, 0x08 },  /* '-' */
    { 0x00, 0x00, 0x60, 0x60, 0x00 },  /* '.' */
    { 0x20, 0x10, 0x08, 0x04, 0x02 },  /* '/' */
    { 0x3E, 0x51, 0x49, 0x45, 0x3E },  /* '0' */
    { 0x00, 0x42, 0x7F, 0x40, 0x00 },  /* '1' */
    { 0x72, 0x49, 0x49, 0x49, 0x46 },  /* '2' */
    { 0x21, 0x41, 0x49, 0x4D, 0x33 },  /* '3' */
    { 0x18, 0x14, 0x12, 0x7F, 0x10 },  /* '4' */
    { 0x27, 0x45, 0x45, 0x45, 0x39 },  /* '5' */
    { 0x3C, 0x4A, 0x49, 0x49, 0x31 },  /* '6' */
    { 0x41, 0x21, 0x11, 0x09, 0x07 },  /* '7' */
    { 0x36, 0x49, 0x49, 0x49, 0x36 },  /* '8' */
    { 0x46, 0x49, 0x49, 0x29, 0x1E },  /* '9' */
    { 0x00, 0x00, 0x14, 0x00, 0x00 },  /* ':' */
    { 0x00, 0x40, 0x34, 0x00, 0x00 },  /* ';' */
    { 0x00, 0x08, 0x14, 0x22, 0x41 },  /* '<' */
    { 0x14, 0x14, 0x14, 0x14, 0x14 },  /* '=' */
    { 0x00, 0x41, 0x22, 0x14, 0x08 },  /* '>' */
    { 0x02, 0x01, 0x59, 0x09, 0x06 },  /* '?' */
    { 0x3E, 0x41, 0x5D, 0x59, 0x4E },  /* '@' */
    { 0x7C, 0x12, 0x11, 0x12, 0x7C },  /* 'A' */
    { 0x7F, 0x49, 0x49, 0x49, 0x36 },  /* 'B' */
    { 0x3E, 0x41, 0x41, 0x41, 0x22 },  /* 'C' */
    { 0x7F, 0x41, 0x41, 0x41, 0x3E },  /* 'D' */
    { 0x7F, 0x49, 0x49, 0x49, 0x41 },  /* 'E' */
    { 0x7F, 0x09, 0x09, 0x09, 0x01 },  /* 'F' */
    { 0x3E, 0x41, 0x41, 0x51, 0x73 },  /* 'G' */
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
};

static void scr_clear(void) { memset(fb, 0, sizeof fb); }

/* s at pixel (x, y), each font pixel scale x scale; characters are 6 x 8 font pixels */
static void scr_text(int x, int y, int scale, int colour, const char *s)
{
    uint16_t c = (colour >> 8 & 0xFF) | (colour & 0xFF) << 8;
    for (; *s; s++, x += 6 * scale) {
        int ch = (unsigned char)*s;
        const unsigned char *g = font5x7[ch < 0x20 || ch > 0x7E ? '?' - 0x20 : ch - 0x20];
        for (int col = 0; col < 5; col++)
            for (int row = 0; row < 8; row++)
                if (g[col] >> row & 1)
                    for (int dy = 0; dy < scale; dy++)
                        for (int dx = 0; dx < scale; dx++) {
                            int px = x + col * scale + dx, py = y + row * scale + dy;
                            if (px >= 0 && px < 128 && py >= 0 && py < 128) fb[py * 128 + px] = c;
                        }
    }
}

static void scr_pixel(int x, int y, int colour)
{
    if (x >= 0 && x < 128 && y >= 0 && y < 128) fb[y * 128 + x] = (colour >> 8 & 0xFF) | (colour & 0xFF) << 8;
}

/* send fb to the panel */
static void scr_show(void)
{
    unsigned char cmd, w[4] = { 0, lcd_x0, 0, lcd_x0 + 127 };
    cmd = 0x2A; lcd_send(0, &cmd, 1); lcd_send(1, w, 4);           /* CASET */
    w[1] = lcd_y0; w[3] = lcd_y0 + 127;
    cmd = 0x2B; lcd_send(0, &cmd, 1); lcd_send(1, w, 4);           /* RASET */
    cmd = 0x2C; lcd_send(0, &cmd, 1); lcd_send(1, fb, sizeof fb);  /* RAMWR */
}

/* a device on the internal I2C (SDA G45, SCL G0: the backlight and the IMU), setting the bus up first time */
static int sys_i2c_dev(int addr, i2c_master_dev_handle_t *d)
{
    static i2c_master_bus_handle_t bus;
    i2c_master_bus_config_t b = {
        .i2c_port = -1, .sda_io_num = SYS_SDA, .scl_io_num = SYS_SCL, .clk_source = I2C_CLK_SRC_DEFAULT,
        .glitch_ignore_cnt = 7, .flags.enable_internal_pullup = 1,
    };
    i2c_device_config_t c = { .dev_addr_length = I2C_ADDR_BIT_LEN_7, .device_address = addr, .scl_speed_hz = 400000 };
    if (!bus && i2c_new_master_bus(&b, &bus) != ESP_OK) { bus = NULL; return -1; }
    return i2c_master_bus_add_device(bus, &c, d) == ESP_OK ? 0 : -1;
}

/* LP5562: enable, internal clock, all channels from their PWM registers, W (the backlight) to level */
static int bl_init(int level)
{
    i2c_master_dev_handle_t d;
    if (sys_i2c_dev(BL_ADDR, &d)) return -1;
    unsigned char w[][2] = { { 0x00, 0x40 }, { 0x08, 0x01 }, { 0x70, 0x00 }, { 0x0E, level } };
    for (int i = 0; i < 4; i++) {
        if (i2c_master_transmit(d, w[i], 2, 50) != ESP_OK) return -1;
        if (i == 0) msleep(1);
    }
    return 0;
}

/* set up the screen and clear it; what it is, or NULL if there isn't one. *ok = 0 if the backlight didn't answer */
static const char *scr_init(int *ok)
{
    static char what[48];
    spi_bus_config_t b = {
        .mosi_io_num = LCD_MOSI, .miso_io_num = -1, .sclk_io_num = LCD_SCLK,
        .quadwp_io_num = -1, .quadhd_io_num = -1, .max_transfer_sz = sizeof fb,
    };
    if (spi_bus_initialize(LCD_HOST, &b, SPI_DMA_CH_AUTO) != ESP_OK) return NULL;
    gpio_reset_pin(LCD_DC);
    gpio_set_direction(LCD_DC, GPIO_MODE_OUTPUT);
    gpio_reset_pin(LCD_RST);
    gpio_set_direction(LCD_RST, GPIO_MODE_OUTPUT);
    gpio_set_level(LCD_RST, 0);
    msleep(10);
    gpio_set_level(LCD_RST, 1);
    msleep(120);

    /* some GC9107s only answer slowly; an ST7735S answers at the first speed */
    uint32_t id = lcd_id(8000000);
    int st = (id & 0xFFFF) == 0x7683 || (id & 0xFFFF) == 0x897C, gc = (id & 0xFFFFFF) == 0x079100;
    if (!st && !gc) {
        id = lcd_id(100000);
        gc = (id & 0xFFFFFF) == 0x079100;
    }
    spi_device_interface_config_t d = { .clock_speed_hz = 40000000, .spics_io_num = LCD_CS, .queue_size = 1 };
    if (spi_bus_add_device(LCD_HOST, &d, &lcd) != ESP_OK) return NULL;
    lcd_cmds(st ? st7735s_init : gc9107_init);
    lcd_x0 = st ? 2 : 0;
    lcd_y0 = st ? 3 : 32;
    snprintf(what, sizeof what, "%s (id %06lx%s)", st ? "ST7735S" : "GC9107",
             (unsigned long)(id & 0xFFFFFF), st || gc ? "" : ", not recognised");
    scr_clear();
    scr_show();
    *ok = bl_init(BL_LEVEL) == 0 && (st || gc);
    return what;
}

/*
 * The IMU: a Bosch BMI270 (accelerometer and gyro) at 0x68 on the internal
 * I2C. It needs Bosch's 8 KB configuration file uploaded at every start-up.
 * Accelerometer +-4 g at 100 Hz, gyro +-500 deg/s at 200 Hz. imu_read()
 * turns the readings into the robot's axes: +x towards the gap between legs
 * 1 and 2, +y 90 degrees anticlockwise from that (seen from above), +z up.
 * Legs 1-6 (hip ids) go clockwise round the body, so leg k points at
 * 30 - 60 (k - 1) degrees. The ATOM lies flat on the leg 1-4 axis, the
 * chip's +x pointing at leg 4, IMU_YAW (found by tipping the robot up at
 * each gap between legs).
 */
#define IMU_ADDR 0x68
#define IMU_YAW  -150.0         /* deg, anticlockwise from the 1-2 gap: where the chip's +x points */
#include "atom/bmi270_config.h"

static i2c_master_dev_handle_t imu;
static double imu_c, imu_s;             /* cos and sin of IMU_YAW, from imu_init() */

static int imu_wr(int reg, int v)
{
    unsigned char w[2] = { reg, v };
    return i2c_master_transmit(imu, w, 2, 50) == ESP_OK ? 0 : -1;
}

static int imu_rd(int reg, unsigned char *b, int n)
{
    unsigned char r = reg;
    return i2c_master_transmit_receive(imu, &r, 1, b, n, 50) == ESP_OK ? 0 : -1;
}

/* the IMU didn't answer or start: drop its handle, so imu_read() fails rather than reading an unconfigured chip */
static int imu_fail(void)
{
    if (imu) i2c_master_bus_rm_device(imu);
    imu = NULL;
    return -1;
}

/* 0 if it's there and its config loaded, -1 if not (1 = no IMU on this host, the Pi's stub) */
static int imu_init(void)
{
    unsigned char id = 0, st = 0, buf[1 + 256];
    imu_c = cos(IMU_YAW * M_PI / 180);
    imu_s = sin(IMU_YAW * M_PI / 180);
    if (sys_i2c_dev(IMU_ADDR, &imu)) return -1;
    if (imu_rd(0x00, &id, 1) || id != 0x24) return imu_fail();                         /* CHIP_ID */
    imu_wr(0x7E, 0xB6);                         /* CMD: soft reset (needs 2 ms) */
    msleep(5);
    imu_wr(0x7C, 0x00);                         /* PWR_CONF: advanced power save off, for the upload (450 us) */
    msleep(5);
    imu_wr(0x59, 0x00);                         /* INIT_CTRL: start of config load */
    for (int i = 0; i < (int)sizeof bmi270_config_file; i += 256) {
        unsigned char a[3] = { 0x5B, (i / 2) & 0x0F, (i / 2) >> 4 };       /* INIT_ADDR_0/1, in words */
        buf[0] = 0x5E;                                                      /* INIT_DATA */
        memcpy(buf + 1, bmi270_config_file + i, 256);
        if (i2c_master_transmit(imu, a, 3, 50) != ESP_OK || i2c_master_transmit(imu, buf, sizeof buf, 100) != ESP_OK) return imu_fail();
    }
    imu_wr(0x59, 0x01);                         /* INIT_CTRL: config load done */
    for (int i = 0; i < 20 && (st & 0x0F) != 1; i++) { msleep(5); imu_rd(0x21, &st, 1); }  /* INTERNAL_STATUS: 1 = init ok */
    if ((st & 0x0F) != 1) return imu_fail();
    imu_wr(0x7D, 0x0E);                         /* PWR_CTRL: accelerometer, gyro, temperature on */
    imu_wr(0x40, 0xA8);                         /* ACC_CONF: 100 Hz, normal filter, performance mode */
    imu_wr(0x41, 0x01);                         /* ACC_RANGE: +-4 g */
    imu_wr(0x42, 0xA9);                         /* GYR_CONF: 200 Hz, normal filter, performance mode */
    imu_wr(0x43, 0x02);                         /* GYR_RANGE: +-500 deg/s */
    imu_wr(0x7C, 0x02);                         /* PWR_CONF: FIFO self wake-up, no power save */
    msleep(50);
    return 0;
}

/* acceleration in g (+1 on z standing level) and rotation in deg/s, in the robot's axes:
   x towards the gap between legs 1 and 2, y 90 degrees anticlockwise from it seen from above, z up */
static int imu_read(double acc[3], double gyr[3])
{
    unsigned char b[12];
    double a[3], g[3], c = imu_c, s = imu_s;
    if (!imu || imu_rd(0x0C, b, 12)) return -1;  /* ACC x y z, GYR x y z, little-endian, chip axes */
    for (int i = 0; i < 3; i++) {
        a[i] = (int16_t)(b[2 * i] | b[2 * i + 1] << 8) * 4.0 / 32768;
        g[i] = (int16_t)(b[6 + 2 * i] | b[7 + 2 * i] << 8) * 500.0 / 32768;
    }
    acc[0] = c * a[0] - s * a[1]; acc[1] = s * a[0] + c * a[1]; acc[2] = a[2];
    gyr[0] = c * g[0] - s * g[1]; gyr[1] = s * g[0] + c * g[1]; gyr[2] = g[2];
    return 0;
}

#else

#define BUS_ECHO 1      /* the Waveshare USB adapter loops TX back to RX; txrx() reads and drops it */

static int fd = -1;

static speed_t baud_const(int baud)
{
    switch (baud) {
    case 9600: return B9600;     case 19200: return B19200;
    case 38400: return B38400;   case 57600: return B57600;
    case 115200: return B115200; case 230400: return B230400;
    case 500000: return B500000; case 1000000: return B1000000;
    default: return 0;
    }
}
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
int main(int argc, char **argv)
{
    const char *dev = argc > 1 ? argv[1] : "/dev/ttyACM0";
    int baud = argc > 2 ? atoi(argv[2]) : 1000000;
    con_init();
    open_port(dev, baud);
    printf("opened %s @ %d\n", dev, baud);
    scr_what = scr_init(&scr_ok);
    imu_st = imu_init();
    t_boot(0);
    printf("type help\n");
    repl();
    close(fd);
    return 0;
}
#endif

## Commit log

2026-09-24 Hector: 2-DOF hexapod walker on 12 SC09 bus servos
    hector.c is a copy of the servo tester (github.com/op12no2/servo) plus
    hexapod commands: stand, legtest, walk (wave, ripple and tripod gaits,
    streamed as one sync write every 20 ms, with a per-servo peak load
    report) and set for the walk parameters.
2026-09-24 add cad files
    [02_hip_cradle.step, 02_hip_cradle.stl, 03_fixed_leg.step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]
2026-09-24 Describe the CAD parts and leg geometry; commit and push without asking
    cad/README.md: what each part is, how they fit together (legs 60 degrees
    apart, hip shafts about 62 mm from the centre, lift axis above the hip),
    and where the foot sits against height, which is the lift servo's lever
    arm. Measured from the STEP files with Open CASCADE.
    CLAUDE.md: point to cad/README.md and say how to load the STEP files;
    add a Git section (commit and push finished changes without asking,
    pull first); fix a stale mention of 800 ms as the default step.
2026-09-26 new body design and longer legs
    [02_hip_cradle.step, 03_fixed_leg.step, 03_fixed_leg.stl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]
2026-09-26 Describe the 220 mm body, cage, lid and longer legs
    cad/README.md: the new body (220 mm disc, spokes and outer ring, central
    wiring cage with a lid), the one-leg assembly file, hips now 90 mm from
    the centre, and the longer leg (foot 42.5 out and 81 below the lift
    axis). The height table now also gives the body's height off the ground
    (below about -120 the hip servos touch down), and a new section lists
    clearances measured by turning the parts in the assembly: the lift's
    foot-down margin is about the same as the old body's; turning a hip
    towards its leg plate's side meets the outer ring at 123 steps at height
    0 (61 at +50, 177 at -60); neighbouring legs don't meet.
    CLAUDE.md: point to the a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
2026-09-26 Legs are all fitted the same way round: say what that means for the hip clearance
2026-09-26 legtest: lift to 700, swing 80, move only the leg under test; gentle walk defaults
    legtest no longer stands first (it still checks all 12 servos reply) and
    moves only the tested leg's two servos, through a new send_leg(); it and
    send_pose() share leg_goals(). Each leg lifts to 700 (189 above centre),
    swings forward 80, back, and down to its stance pose. Tested on the robot.
    The walk defaults go back to the gentle first-walk settings (wave, step
    800, stride 50, lift 70, height 0) while the gait is retuned for the new
    body; not yet walked with.
    [hector.c]
2026-10-01 Per-id goal offset table (lifts 7 and 11 +20); servo 9 replaced
    offset[] is added to every goal sent, by move and by leg_goals(), so
    move 7 511 sends 531; it replaces the unused per-leg trims. Reads stay raw.
    Tested off the robot only: the packets for ids with offsets were checked
    against absent ids (nothing moved). The new servo 9 answers with the
    default overload settings.
    [hector.c]
2026-10-01 CLAUDE.md: drop a repeated note on the clamps
2026-10-01 ident [id]: twitch each id (default 1-12) in turn, 1 s apart
    +30 from its present position and back, printing which leg legs[] says
    the id belongs to. Tested off the robot only: the packets were checked
    against an absent id (nothing moved).
    [hector.c]
2026-10-01 calibrate: even out the load on the six feet; offset [id val]
    calibrate stands, then nudges the lift offsets from where they are until
    every lift carries the same load, and prints the table as C. offset shows
    or sets an entry until exit. Run on the robot: 6 rounds, from 0-12% load to
    6-7.5% on every lift; those offsets are now the table's.
2026-10-01 CLAUDE.md: note startup calibration and the ATOM screen as future ideas
2026-10-01 Wiring: ATOM S3R schematic and notes
    ATOM G38/G39 to the adapter's UART header (jumper A), powered from the
    battery through the MPM3610 buck and a Schottky, so its USB-C stays free
    for flashing. Pins, levels and the 5V/VBUS net checked against the ATOM
    S3R and adapter schematics; not built yet.
2026-10-02 ATOM S3R build: the same hector.c under ESP-IDF, in atom/
    hector.c gets an I/O section with an ESP_PLATFORM half (bus on UART1,
    TX G38 / RX G39, into the adapter's H2 with the jumper in A; console on
    the ATOM's USB-Serial/JTAG) and a POSIX half (the old code). The rest is
    shared: txrx, the line editor and walk go through bus_*, con_*,
    sigint_* and tick_*. On the ATOM, ctrl-c arrives as a byte, which walk
    checks for, and the line editor treats CR LF as one enter.
    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
2026-10-05 Startup self test, logged on the ATOM's screen, then Hi!
    selftest (at startup on both hosts, and as a command) reads only: servos
    reply, battery, temperature, error bits, overload protection settings,
    positions, load. On the ATOM each check also goes on the 128x128 screen
    (GC9107 or ST7735S, probed as M5GFX does; LP5562 backlight), then Hi!
    coloured by the worst result with any problems under it. Tested on the
    robot; this ATOM has the ST7735S.
    [hector.c]
2026-10-05 loads: stream every servo's load and position error
    For seeing what pushing on the robot does. Reads only; about 80 sweeps of
    all 12 a second, with the seconds on the ATOM's screen to time presses
    by. Tested on the robot; findings (presses barely move the feet) are in
    CLAUDE.md.
    [hector.c]
2026-10-05 IMU: BMI270 on the ATOM, imu command, tilt in the self test
    The BMI270 shares the internal I2C with the backlight; it needs Bosch's
    8 KB config file (atom/bmi270_config.h, BSD-3) uploaded at start-up.
    imu [secs] streams acceleration, rotation and tilt. Tested on the robot:
    tipping each edge up shows the chip's axes are the robot's (+x forward,
    +y left, +z up), 6-9 deg for a couple of cm against 0.1 deg of noise.
    [hector.c]
2026-10-05 bow: tip it at an edge and it bows that way; the ATOM stands at boot
    bow stands, takes the IMU as level, and when it's tipped up at an edge and
    put down, lifts the two legs nearest that edge to 700 over a second (the
    body is designed to come down on that edge) and stands again. At power-on
    the ATOM stands after the self test unless something failed. Tested on the
    robot.
    [hector.c]
2026-10-05 bow: legs by number round the body; IMU in the cage's frame; hold 500 ms
    The ATOM now sits in the new top cage on the leg 1-4 axis; imu_read()
    rotates its readings so +x is the gap between legs 1 and 2 (legs 1-6 go
    clockwise). bow picks the two legs either side of the tilt by that,
    ignores set-down jolts when finding the direction, takes their lifts to
    700, holds 500 ms and stands. The battery's 'high' limit is 8.7 V (a
    full 2S reads 8.6 on some servos). Tested on the robot between legs 1
    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
2026-10-05 legs[]: the layout for the current numbering (1-6 clockwise)
    Legs 1-6 go clockwise seen from above and the walk goes towards the 6-1
    gap (legtest 1 swings leg 1 towards 6), so 1-3 are the right side front
    to back and 6-4 the left. legs[] had an older wiring, with the sides
    swapped (turns were reversed) and 4 and 6 in each other's rows. hip_dir
    is unchanged; the tripod groups are the same. Checked with legtest and
    ident on the robot; not walked yet with the new layout.
    [hector.c]
2026-10-05 sit: all lifts to 1000, the switch-off pose
    The body sits on the ground with the legs pointing up inside it and no
    load on the servos (the user's move 7-12 1000 1000). Tested on the
    robot: the lifts reached 1000 plus offset within 2 steps (lift 11
    stopped 8 short).
    [hector.c]
2026-10-05 sit: cap at the servos' angle limit (1003)
    Lift 11 (offset +9) stopping at 1001 wasn't the servo falling short: its
    goal of 1009 was clamped by its own limit. Build only; the change just
    asks for what the servos were already doing.
    [hector.c]
2026-10-05 selftest: checks before standing, then standing checks
    t_pre() is the go/no-go for standing up; t_standing() needs the weight on
    the feet: the load on each foot, sag, level, the highest load and the
    battery under load. At power-on the ATOM runs one, stands, runs the
    other, then says Hi!. The selftest command runs the standing half only
    if stand ran last (not sit). Tested on the robot.
    [hector.c]
2026-10-05 selftest: loosen the feet check to 8%
    Standing loads only read 0, 6, 7.5, 9% (one value per step a foot is
    pushed up), and with the feet on 1-3 steps each stand leaves a different
    foot at 0; calibrate couldn't settle either. Findings in CLAUDE.md.
    Tested on the robot.
    [hector.c]
2026-10-05 Lifts at I gain 1; the self test checks the gains
    With I 0 a lift held the body 1-4 steps off its goal and its load read
    only 0/6/7.5/9%, so each stand landed differently and calibrate was
    balancing noise. With I 1 (set in the servos' EPROM) the feet stand
    within 1.5% every time and calibrate balances in one round with the
    same offsets. The self test now checks P/D/I (a replaced servo comes with
    I 0), waits 1 s after standing for the I term, and the feet check is
    back at 3%. Tested on the robot standing; not walked with I 1 yet.
    [hector.c]
2026-10-05 Eyes: an idle loop, and blinking eyes in place of Hi!
    The line editor now waits for keys in 20 ms slices and runs alive() in
    between: for now the eyes on the ATOM's screen, almond-shaped with a
    blue iris, blinking every few seconds (the lid comes down from the
    top), glancing about now and then, and able to look in a given
    direction (for facing, next). Their whites show the self test's result,
    with its first problem under them. Tested on the robot.
    [hector.c]
2026-10-05 Servo watch in the idle loop
    alive() reads one servo per tick, round robin (load, voltage,
    temperature, error bits), and after each sweep shows the worst problem
    under the eyes and on the console: warnings for a low battery, warm
    servos or error bits; for a flat battery, overheating, overload, a load
    held high or a servo not replying it also sits, if standing. Tested on
    the robot that it stays quiet when all's well; the warnings weren't
    provoked. Notes that D1 is now fitted.
    [hector.c]
2026-10-05 Bowing as a behaviour; knocked over, it sits
    The bow command is gone: while it's standing and waiting, tip it up
    between two legs and put it down, and it bows that way, stands, and the
    eyes look that way. Level is taken again after every command and bow.
    Gravity off z for a second makes it sit. The standing feet check is at
    5% (3% fired on boots). Tested on the robot: four tips, the right legs,
    the eyes looking that way.
2026-10-05 Facing: a bow sets the front, and the face turns to it
    Any of the six gaps can be the walk's front (set_front() redoes side,
    row and hip_dir; gap 6 reproduces legs[]). A bow sets it to the gap it
    bowed on, and front [1-6] shows or sets it. The face (eyes and now a
    mouth) is drawn turned so its mouth points at the front, and turns
    there smoothly, also while bowing; the mouth smiles, goes flat or frowns
    with the status. Tested on the robot (bows, the face turning); walking
    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
2026-10-05 Bowing: tell a tip from a slide by its rotation
    Sliding it along read as a tilt and made it bow. A tip now also needs
    the gyro's rotation, added up to the biggest tilt, to be at least half
    that tilt, held over 3 deg for 250 ms. Tested on the robot: eight pushes
    and pulls (8-11 deg of 'tilt', 0.4-1.3 deg of rotation) rejected, two
    tips (14 deg) bowed.
2026-10-05 Pushed, it walks that way; tripod by default
    A slide (rotation well under its apparent tilt) makes it walk the way it
    was pushed: the nearest gap becomes the front, the face turns there, and
    it walks 2, 4 or 6 cycles for a short, medium or long push. The way and
    distance come from the acceleration added up twice from a little before
    the push showed (taking its first jolt sometimes pointed 180 deg off).
    The default gait is tripod. Tested on the robot: 18 pushes, all six
    directions; still to be tuned.
    [hector.c]
2026-10-05 Safety: wait for hands off, and go limp on contact while walking
    After a tip or a push the face turns, then it waits 1.5 s of stillness
    before moving, and doesn't move if touched again. While walking, a leg
    over 50% load, no weight on any foot (picked up), or a hard knock (over
    120 deg/s or 1 g) turns torque off on all twelve; the face goes sleepy
    with 'limp' until stand, which turns torque back on. The servo watch
    prints a drifting battery voltage once, not on every 0.1 V. Tested on
    the robot: normal walks complete (limits raised from 60 deg/s and 0.5 g,
    which a walk reached); hands off and picked up not yet confirmed.
    [hector.c]
2026-10-05 Review fixes for the ATOM: no echo wait, broadcast torque, watch and editor edge cases
    txrx: only read back a TX echo where the adapter makes one (BUS_ECHO: 1 on
    the Pi's USB adapter, 0 on the ATOM's H2 link). Asking for as many bytes as
    were sent, when the reply is shorter, waited the whole 50 ms timeout on every
    write and 1-byte read; stand measured 1.85-2.0 s on the ATOM, 1.25-1.4 after.
    stand and go_limp turn torque on and off with one broadcast write instead of
    twelve writes with replies, so an all stop releases every servo at once
    (the SC09s honour it: checked with a raw broadcast and rb 1-12 0x28).
    watch: the battery minimum only counts servos whose last read replied; a
    servo's volt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
    [hector.c]
2026-10-06 Backtrack: a tip walks it away for 5 s; safety checks, push-to-walk and the bow removed
    The slide and safety behaviour was erratic on the robot, so simplify:
    - lifting an edge and putting it down (the bow's trigger) now makes it
    walk away from the lifted edge for TIP_WALK_S (5) seconds, with the
    current gait and stride; walk() takes a time limit for it
    - removed: hands_off(), the all stop in walk (load, picked up, gyro,
    jolt), go_limp() and the limp face; safety to be revisited before
    the grandchildren get it
    - removed: push_to() and the slide history; a slide still fails the
    tip test (rotation) and does nothing
    - removed: bow_to(); BOW_* renamed TIP_*, bow_level() imu_level()
    Bui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
    [hector.c]
2026-10-06 Tidy up after the backtrack: stale comments, a redundant declaration, a dead redraw flag
    - tips(): drop eyes_dirty before the tip walk, left from when the eyes
    looked towards a bow; the face redraws itself as it turns
    - drop walk()'s forward declaration (it's defined above tip_walk())
    - comments, help and README: the IMU's x is towards the 1-2 gap, not
    "forward" (any gap can be the front); the header's command list;
    what alive() does; face_wait(); selftest's help mentions the gains
    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
2026-10-06 Tip walk: start within half a second, and the face turns while it walks
    - the tip walk no longer waits 0.7 s for the face or stands for 1.2 s
    first: walk() takes `quick`, which skips the stand if it's already
    standing at this height and only checks the servos. From put-down to
    the first step is now the 300 ms settle plus that check
    - walk() calls eyes() each tick, so the face turns to the new front in
    one go as it walks (and blinks in any walk). eyes() draws on one
    tick and sends on the next while walking, to keep the ticks at 20 ms
    - walk reports its longest tick, to show whether the face stretches them
    - face_wait() removed
    Built warning-free for the Pi and the ATOM. Not flashed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
    [hector.c]
2026-10-06 walk: report how many ticks were late and how long the face took
    The first tip walks on the robot looked fine, with a longest tick of
    36 ms. That isn't a missed read (the timeout is 50 ms), so it is
    probably the face's draw; the report now counts ticks over 25 ms and
    gives the longest eyes() call, to tell.
    Built warning-free for the Pi and the ATOM; not flashed.
    [hector.c]
2026-10-06 Face: no divisions in the pixel loop
    A tip walk on the robot reported 44 of 362 ticks late and the face's
    draw taking up to 34 ms. The ESP32-S3 has no float divide, and the loop
    called __divsf3 twice and __truncdfsf2 once per pixel over most of the
    screen. It now multiplies by constant reciprocals, takes mood and the
    lid as floats beforehand, and skips the eye and mouth tests outside
    their rows; the ATOM build's loop calls only scr_pixel.
    Compared with the old loop on the Pi over 36000 frames: 17 differ, by
    one pixel each. Built warning-free for both hosts. Not flashed: the
    draw's time on the ATOM is not yet measured.
    [hector.c]
2026-10-06 Tip: the face turns during the lift; nothing is drawn while walking
    Simpler, at the user's suggestion. Drawing the face from the walk loop
    worked (no late ticks once the draw was 17 ms), but a frame filled the
    whole 20 ms tick, so it is out again, with the draw/send split.
    - tips() sets the front to the gap opposite the lifted edge as soon as
    the lift passes the tip tests, while it is still in the hand, so the
    idle loop turns the face there; it goes back if it wasn't a tip
    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
2026-10-06 CLAUDE.md: lift 9's higher walking load isn't the servo, the weight or the joint
2026-10-06 CLAUDE.md: the servos' measured top speed, and what a walk asks of them
